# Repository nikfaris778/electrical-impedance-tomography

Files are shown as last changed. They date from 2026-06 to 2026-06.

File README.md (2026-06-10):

# Electical Impedance Tomography with Embroidered Electrodes





## 📌 Project Overview
This repository contains the MicroPython firmware and MATLAB simulation scripts for a 16-channel, 3D Electrical Impedance Tomography (EIT) system. Developed as part of a Master of Engineering (MEng) thesis, the project aimed to bridge the gap between low-cost analog hardware and true volumetric impedance imaging using custom CNC-embroidered textile electrodes (HC40 silver-plated thread).

Due to hardware compliance voltage limitations discovered in the V2.0 PCB iteration, the physical system was mathematically validated via synthetic forward modeling. The MATLAB scripts provided here rigorously prove the viability of the system's 3D cross-planar opposite-drive architecture against simulated hardware noise floors.

## 📂 Repository Structure

```text
├── /firmware                  # MicroPython code for the RP2040 (Raspberry Pi Pico)
│   ├── ad5933_wakeup.py       # AD5933 initialisation
│   ├── eit_driver.py          # I2C driver for the AD5933 Impedance Converter
│   └── MUX_control.py         # GPIO routing logic for the 16-channel matrix
│
├── /simulations               # MATLAB scripts using the EIDORS toolbox
│   ├── ValidationCode.m       # Core 3D EIT simulation (Single Target)
│   ├── SpatialComparison.m    # Multi-quadrant spatial variance loop
│   └── README_Simulations.md  # Specific instructions for EIDORS dependencies
│
├── /hardware_docs             # Schematics and PCB Layouts
│   ├── EIT_CONNECTIONS.pdf    # Patient protection block layout
│   ├── EIT_CURRENTSTAGE.pdf   # Analogue front end layout
│   ├── EIT_MULTICONTROLLER.pdf # Pi Pico 2 arrangement with pins
│   ├── EIT_MUXERS.pdf         # Multiplexer routing arrangement
│   └── EIT_board.PcbPrj       # Altium PCB project
└── README.md                  # This document
```
## 🧠 System Architecture
1. Hardware & Firmware Topology
- The physical system utilizes a four-pole (Kelvin) measurement strategy to mathematically negate the high and variable contact impedance ($Z_{contact}$) of the dry textile electrodes.
- Excitation Stage: Enhanced Howland Current Pump (designed for 1mA AC).
- Sensing Stage: AD8221 Instrumentation Amplifier.
- Impedance Converter: AD5933.
- Firmware Protocol: The MicroPython state machine dictates a dual-ring, cross-planar opposite-drive sequence (skip 8). This forces out-of-plane vertical current density vectors ($J_z$) critical for depth-resolved 3D tomography.

2. MATLAB / EIDORS Simulation
To validate the architecture, the MicroPython switching matrix was algorithmically mirrored in EIDORS.
- Noise Injection: Additive White Gaussian Noise (AWGN) at 40dB SNR was injected to simulate the real-world thermal noise limits of the AD8221.
- Inverse Solver: The system utilizes Time-Difference EIT with NOSER Regularization to compensate for the inherently low central sensitivity of the Jacobian matrix, successfully isolating 3D volumetric anomalies.

## 🚀 Getting Started
# Running the EIDORS Simulations
1. Ensure you have MATLAB installed.
2. Download and install the EIDORS 3.11 Toolbox.
3. In the MATLAB console, initialize EIDORS by running:
```matlab
run /path/to/eidors/startup.m
```
4. Open and run validation_3D.m to generate the 3D thresholded tomograms and 2D cross-sectional slices.
# Flashing the Firmware
1. Flash your Raspberry Pi Pico with the latest MicroPython UF2 bootloader.
2. Open the /firmware directory in an IDE like Thonny.
3. Upload main.py, ad5933.py, and mux_control.py to the Pico's root directory.

## ⚠️ Known Hardware Limitations & V3.0 Roadmap
This section documents critical system bring-up findings for future researchers.The V2.0 hardware iteration experienced a severe power domain mismatch ("Compliance Voltage Paradox"). The $\pm 9\text{V}$ analog supply required by the Howland Current Pump to drive high-impedance biological loads forward-biased the internal ESD diodes of the 3.3V CD74HC4067 multiplexers, causing catastrophic CMOS latch-up.

# V3.0 Recommendations:
1. Routing Matrix: Replace the logic-level CMOS multiplexers with high-voltage bipolar analog switches (e.g., Analog Devices ADG1406 or ADG1606) powered directly from the $\pm 9\text{V}$ analog rails.
2. Textile Interfaces: Implement active-electrode buffer topologies directly on the embroidered fabric substrate to combat the long-term oxidation of the HC40 silver thread.
3. Verification: Mandate SPICE transient analysis prior to Gerber generation to ensure safe mixed-signal boundary transitions.

## 📝 License
This project is open-source and available under the MIT License.

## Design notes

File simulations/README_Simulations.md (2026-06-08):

# Synthetic Validation Environment (EIDORS 3D)

This directory contains the MATLAB simulation scripts utilized to mathematically validate the 3D opposite-drive architecture of the EIT system. 

Because physical biological validation was precluded by a power domain mismatch (CMOS latch-up) on the V2.0 hardware, these scripts serve as the definitive proof of the system's underlying firmware state machine and analog sensitivity limits.

## 🧰 Prerequisites
To run these scripts, you must have the following installed:
* **MATLAB** (Tested on R2022a and newer)
* **EIDORS Toolbox** (Electrical Impedance Tomography and Diffuse Optical Tomography Reconstruction Software) - Version 3.11 or newer.

[Download EIDORS here](http://eidors3d.sourceforge.net/download.shtml)

## ⚙️ Setup Instructions
EIDORS must be initialized in your MATLAB workspace before running the simulation scripts.
1. Download and extract the EIDORS toolbox to your local machine.
2. Open MATLAB.
3. In the command window, run the EIDORS startup script:
   ```matlab
   run('C:\Path\To\Your\eidors3.11\eidors\startup.m')
4. You should see EIDORS: <Version> print in the console. You are now ready to run the simulations.

## 📄 File Manifest
```text
ValidationCode.m
```
The core validation script. It builds a 16-electrode, dual-ring cylindrical mesh and simulates a central non-conductive inclusion (representing an acrylic rod). It applies the 4-pole cross-planar firmware protocol, injects hardware noise, and outputs a thresholded 3D isosurface and 2D Z-axis cross-sections.

```text
SpatialComparison.m
```
A multi-target iterative script. It loops the forward and inverse solvers across three distinct XY coordinates (Dead Center, Top-Left, Bottom-Right) and generates a side-by-side comparative plot. This formally proves that the NOSER-regularized solver is robust against the inherently low central sensitivity of the EIT Jacobian matrix.

## 🎛️ Key Parameters for Experimentation
If you wish to modify the simulations to test different hardware constraints, look for the following variables in the scripts:
1. SNR_dB (Default: 40): Controls the Additive White Gaussian Noise (AWGN). 40dB represents the calculated thermal noise floor and quantization error of the V2.0 AD8221/AD5933 frontend. Lowering this value simulates a noisier PCB.
2. imdl.hyperparameter.value (Default: 1.0): The $\lambda$ tuning knob for the NOSER regularization algorithm.
   - Increase this value (e.g., 10.0) to heavily penalize boundary noise (results in a blurry, over-regularized image).
   - Decrease this value (e.g., 0.1) to reduce the penalty (results in high spatial resolution but severe peripheral noise artifacts).

## ⚠️ Important Note on Spatial Coordinates
The simulated saline tank has an absolute radius of 1.0. When modifying the $X$ and $Y$ coordinates of the acrylic rod, ensure that the outer edge of the rod does not exceed the tank boundary.If the condition sqrt(X^2 + Y^2) + Radius > 1.0 is met, the inclusion will physically clip outside the finite element mesh, and the solver will throw a NaN boundary exception.

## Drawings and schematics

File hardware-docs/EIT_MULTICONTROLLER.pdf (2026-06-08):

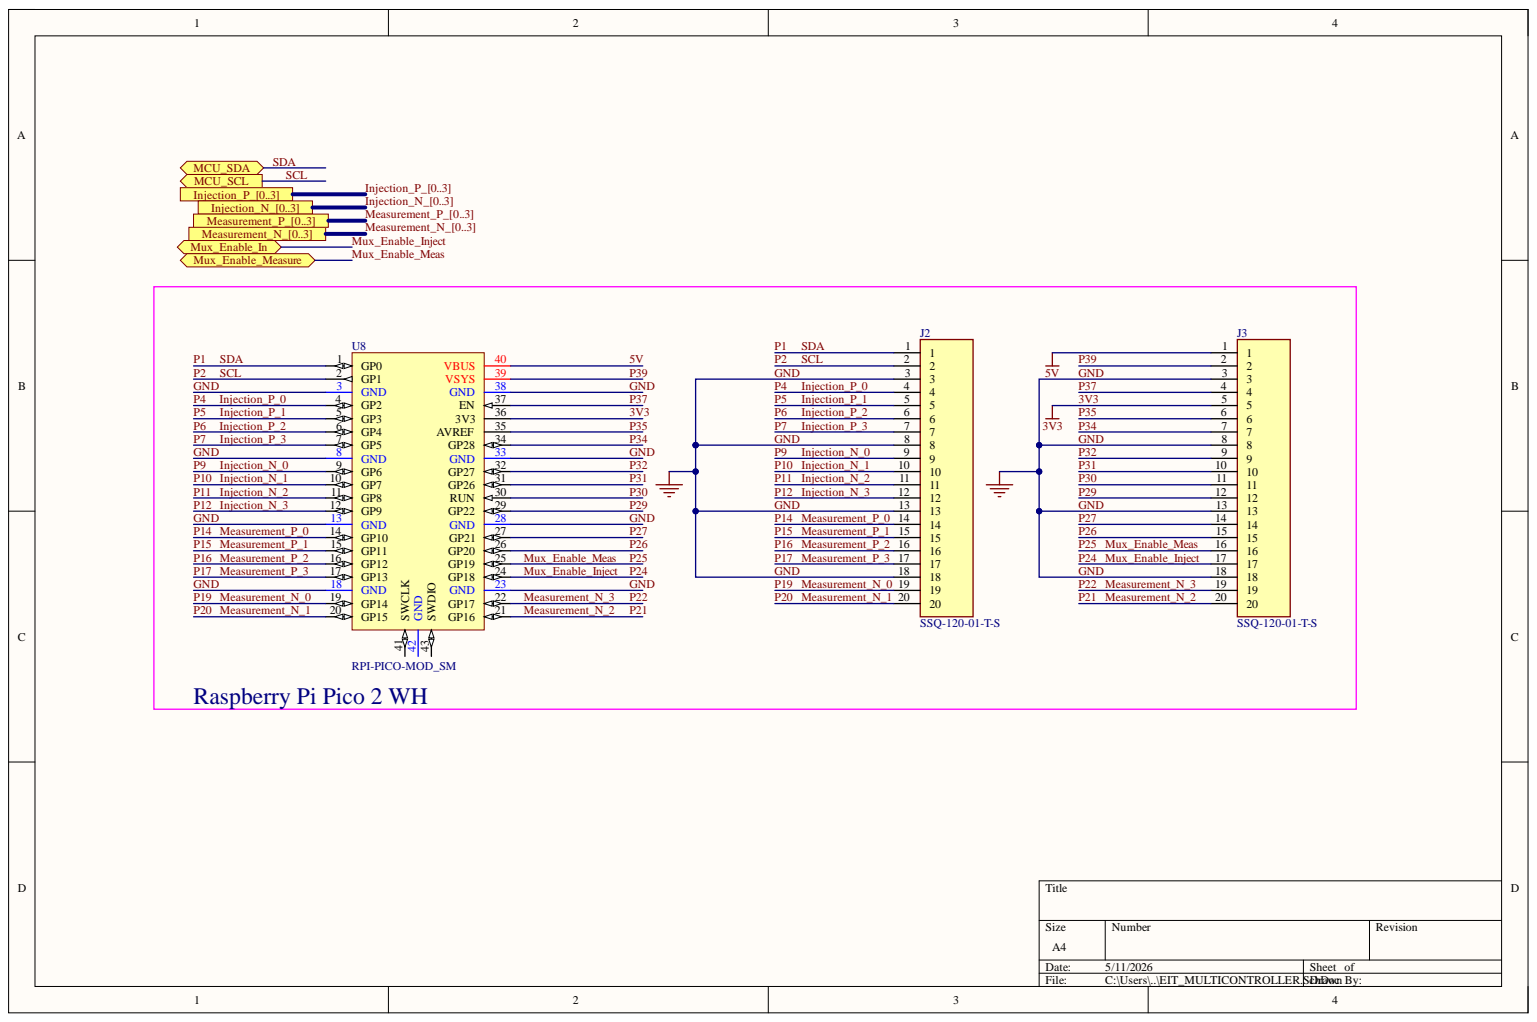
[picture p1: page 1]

Raspberry Pi Pico 2 WH

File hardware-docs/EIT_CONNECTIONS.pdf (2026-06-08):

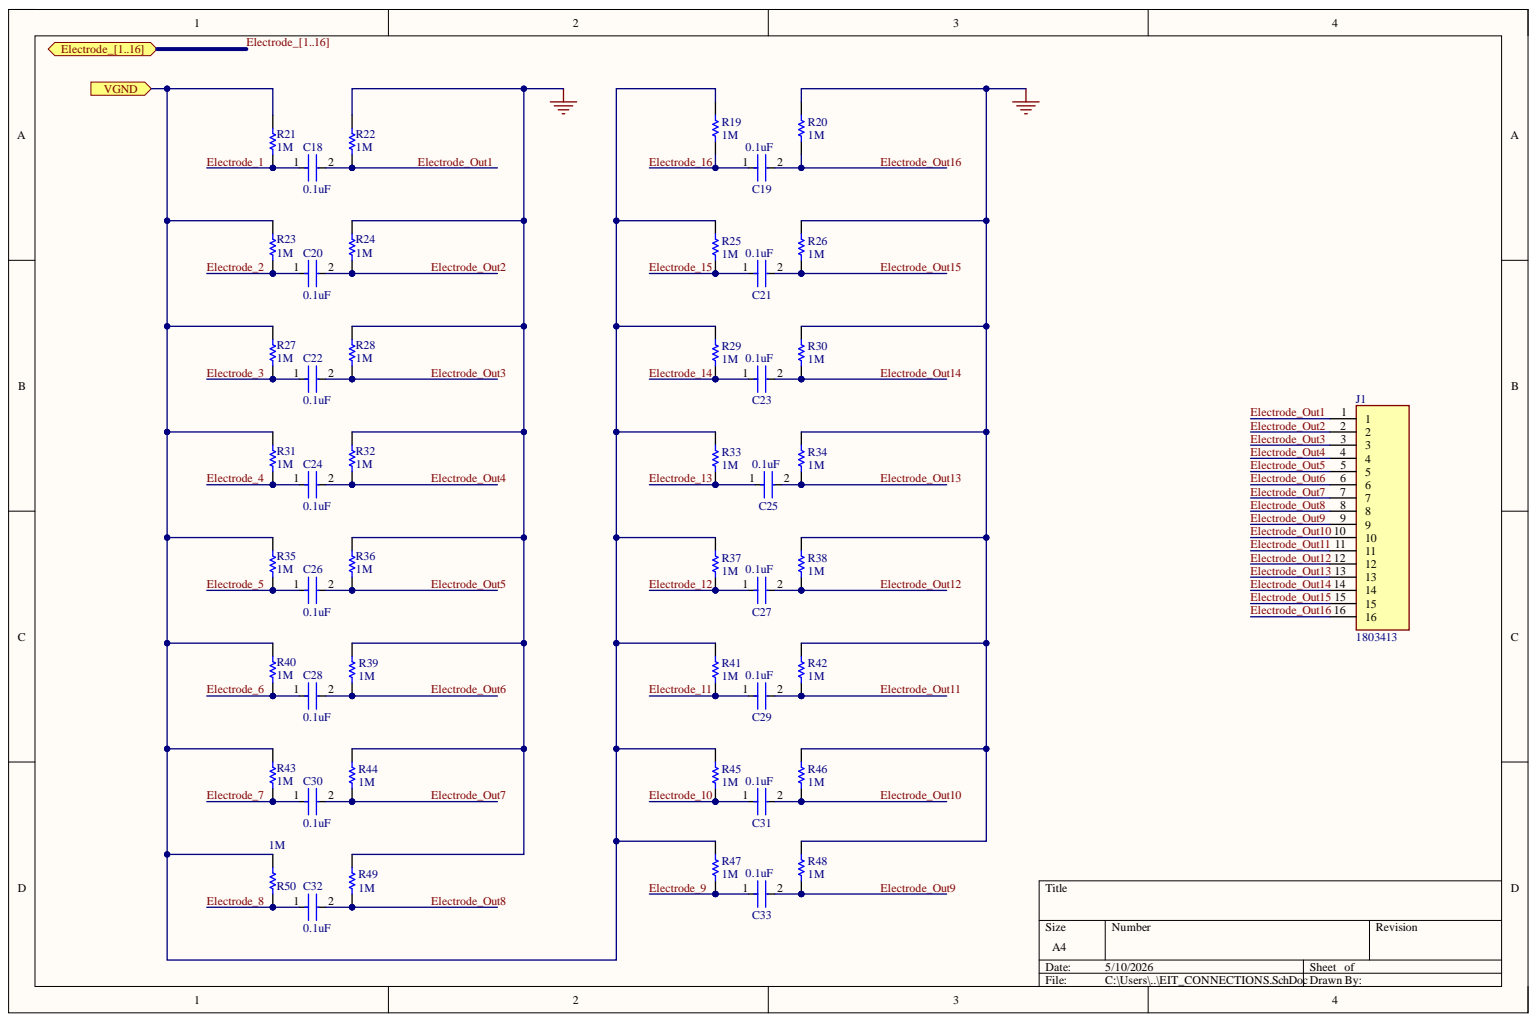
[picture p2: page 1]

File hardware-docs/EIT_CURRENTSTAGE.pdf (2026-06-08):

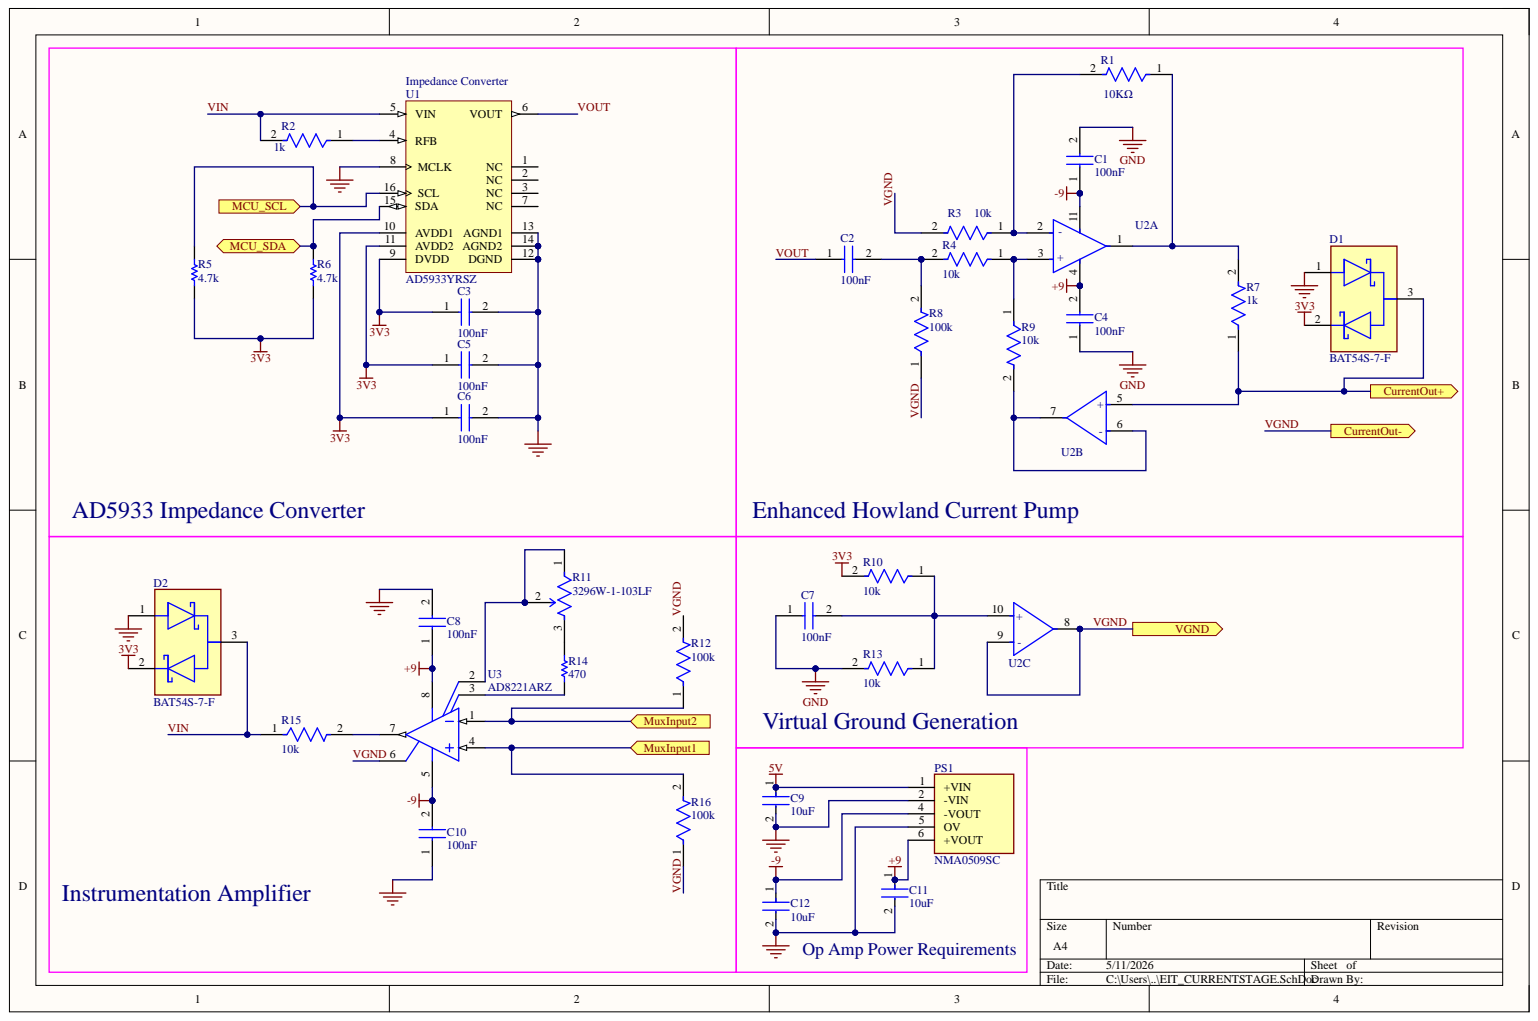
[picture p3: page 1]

AVDD2 11

R5 4.7k | DVDD 9

-VIN 2

10uF | -VOUT 4

OV 5
+VOUT 6

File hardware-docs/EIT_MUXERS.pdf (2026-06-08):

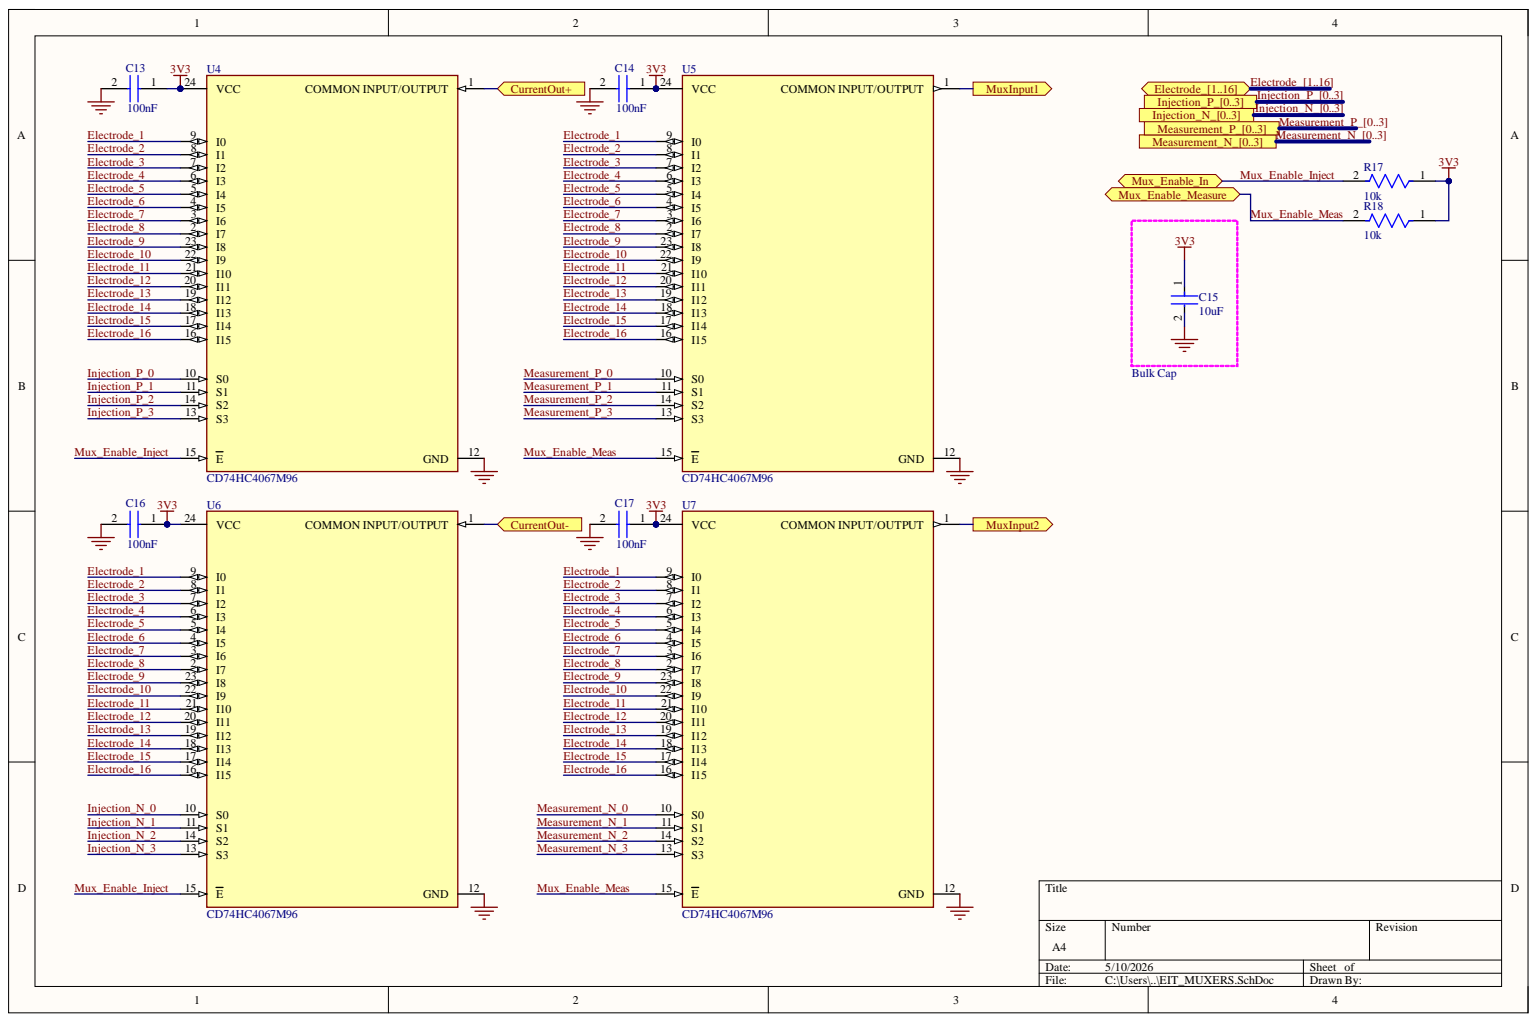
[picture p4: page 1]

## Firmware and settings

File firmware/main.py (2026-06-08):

import machine
import time

# --- Import your custom modules ---
from ad5933_driver import AD5933_EIT
from eit_routing import generate_eit_sequence

# 1. Initialize your hardware objects
chip = AD5933_EIT()
routing_table = generate_eit_sequence()

# 2. Setup your Pico MUX Pins here
# mux_source = [...]
# mux_sink = [...]
# etc...

def run_phase_5_calibration():
    print("Starting Calibration on Dummy Resistor...")
    # You will command the MUXes to Channels 0 and 1 here
    # You will trigger an I2C read from the AD5933 here
    # chip.calibrate(1000, raw_real, raw_imag)

def run_phase_6_sweep():
    print("Starting Full 16-Channel Sweep...")
    frame_data = []
    
    for step in routing_table:
        src, snk, meas_p, meas_n = step
        # 1. Switch MUX pins using src, snk, meas_p, meas_n
        # 2. Trigger AD5933 I2C read
        # 3. Calculate impedance: z = chip.calculate_impedance(real, imag)
        # 4. frame_data.append(z)
        
    print("Sweep Complete. Data:", frame_data)

# --- Main Execution Loop ---
run_phase_5_calibration()
# run_phase_6_sweep()

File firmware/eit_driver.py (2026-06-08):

from machine import Pin, I2C
import time
import struct
import json

class AD5933:
    """Hardware Abstraction Layer for the AD5933 Impedance Converter."""
    ADDR = 0x0D
    
    # Register Map
    REG_CTRL_HB = 0x80
    REG_CTRL_LB = 0x81
    REG_START_FREQ_1 = 0x82
    REG_FREQ_INC_1 = 0x85
    REG_NUM_INC_1 = 0x88
    REG_SETTLING_CYCLES_1 = 0x8A
    REG_STATUS = 0x8F
    REG_REAL_DATA_1 = 0x94
    REG_IMAG_DATA_1 = 0x96

    # Control Commands
    CTRL_STANDBY = 0xB0
    CTRL_INIT_START_FREQ = 0x10
    CTRL_START_FREQ_SWEEP = 0x20
    CTRL_INC_FREQ = 0x30
    
    def __init__(self, i2c_bus, ext_clk=16776000):
        self.i2c = i2c_bus
        self.clk = ext_clk
        self.verify_connection()
        self.reset()

    def verify_connection(self):
        devices = self.i2c.scan()
        if self.ADDR not in devices:
            raise RuntimeError("AD5933 not found on I2C bus. Check 3V3 rail and SDA/SCL pull-ups.")
        print("AD5933 verified at 0x0D.")

    def write_reg(self, reg, value):
        self.i2c.writeto_mem(self.ADDR, reg, bytes([value]))

    def read_reg(self, reg):
        return self.i2c.readfrom_mem(self.ADDR, reg, 1)[0]

    def reset(self):
        # Reset command to Control Register Low Byte
        self.write_reg(self.REG_CTRL_LB, 0x10)
        time.sleep_ms(10)
        self.set_standby()

    def set_standby(self):
        self.write_reg(self.REG_CTRL_HB, self.CTRL_STANDBY)

    def program_sweep(self, start_hz, inc_hz, num_inc, settling_cycles):
        """Calculates and loads the 24-bit frequency words."""
        # Calculate Start Frequency Code
        start_code = int((start_hz / (self.clk / 4)) * (2**27))
        self.write_reg(self.REG_START_FREQ_1, (start_code >> 16) & 0xFF)
        self.write_reg(self.REG_START_FREQ_1 + 1, (start_code >> 8) & 0xFF)
        self.write_reg(self.REG_START_FREQ_1 + 2, start_code & 0xFF)

        # Calculate Increment Code
        inc_code = int((inc_hz / (self.clk / 4)) * (2**27))
        self.write_reg(self.REG_FREQ_INC_1, (inc_code >> 16) & 0xFF)
        self.write_reg(self.REG_FREQ_INC_1 + 1, (inc_code >> 8) & 0xFF)
        self.write_reg(self.REG_FREQ_INC_1 + 2, inc_code & 0xFF)

        # Number of increments (9-bit limit, max 511)
        self.write_reg(self.REG_NUM_INC_1, (num_inc >> 8) & 0x01)
        self.write_reg(self.REG_NUM_INC_1 + 1, num_inc & 0xFF)

        # Settling time cycles (D10-D9 for multiplier, D8-D0 for cycles)
        # Using 1x multiplier for standard EIT frequencies
        self.write_reg(self.REG_SETTLING_CYCLES_1, (settling_cycles >> 8) & 0x07)
        self.write_reg(self.REG_SETTLING_CYCLES_1 + 1, settling_cycles & 0xFF)

    def measure_single_point(self):
        """Executes a single point measurement with strict polling."""
        self.write_reg(self.REG_CTRL_HB, self.CTRL_INIT_START_FREQ)
        time.sleep_ms(5) # Allow internal DC bias to settle
        self.write_reg(self.REG_CTRL_HB, self.CTRL_START_FREQ_SWEEP)

        # Poll Status Register for Valid Data (Bit 1)
        timeout = time.ticks_add(time.ticks_ms(), 100)
        while not (self.read_reg(self.REG_STATUS) & 0x02):
            if time.ticks_diff(timeout, time.ticks_ms()) < 0:
                raise TimeoutError("AD5933 conversion timed out.")

        # Read 16-bit Two's Complement Data
        real_high = self.read_reg(self.REG_REAL_DATA_1)
        real_low = self.read_reg(self.REG_REAL_DATA_1 + 1)
        imag_high = self.read_reg(self.REG_IMAG_DATA_1)
        imag_low = self.read_reg(self.REG_IMAG_DATA_1 + 1)

        real = struct.unpack('>h', bytes([real_high, real_low]))[0]
        imag = struct.unpack('>h', bytes([imag_high, imag_low]))[0]

        self.set_standby()
        return real, imag

class MUX_Matrix:
    """Manages the 16 independent GPIOs for the 4-Pole MUX array."""
    def __init__(self):
        # Mapped strictly to schematic Multicontroller_9.jpg
        self.inj_p_pins = [Pin(i, Pin.OUT) for i in (2, 3, 4, 5)]
        self.inj_n_pins = [Pin(i, Pin.OUT) for i in (6, 7, 8, 9)]
        self.meas_p_pins = [Pin(i, Pin.OUT) for i in (10, 11, 12, 13)]
        self.meas_n_pins = [Pin(i, Pin.OUT) for i in (14, 15, 16, 17)]
        
        # Enable Pins (Active Low)
        self.en_inject = Pin(18, Pin.OUT, value=1) 
        self.en_measure = Pin(19, Pin.OUT, value=1)

    def disable_all(self):
        """Break-before-make absolute enforcement."""
        self.en_inject.value(1)
        self.en_measure.value(1)
        time.sleep_us(10) # 10us guard band for logic switching

    def set_address(self, pins, channel):
        """Writes binary address to specific MUX S-lines."""
        for i in range(4):
            pins[i].value((channel >> i) & 1)

    def route_frame(self, inj_p, inj_n, meas_p, meas_n):
        """Executes a surgical 4-pole routing change."""
        self.disable_all()
        
        self.set_address(self.inj_p_pins, inj_p)
        self.set_address(self.inj_n_pins, inj_n)
        self.set_address(self.meas_p_pins, meas_p)
        self.set_address(self.meas_n_pins, meas_n)
        
        # Re-enable the paths
        self.en_inject.value(0)
        self.en_measure.value(0)
        
        # Settle delay for the Howland Pump's Virtual Ground RC constant
        time.sleep_us(500)
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

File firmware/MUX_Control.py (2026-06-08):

# MUX control tests
from machine import Pin
import time

# 🚨 REPLACE these numbers with your actual GP pin numbers! 🚨
# Group them by MUX to make your life easier when probing.
mux_1_pins = [Pin(2, Pin.OUT), Pin(3, Pin.OUT), Pin(4, Pin.OUT), Pin(5, Pin.OUT)]
mux_2_pins = [Pin(6, Pin.OUT), Pin(7, Pin.OUT), Pin(8, Pin.OUT), Pin(9, Pin.OUT)]
mux_3_pins = [Pin(10, Pin.OUT), Pin(11, Pin.OUT), Pin(12, Pin.OUT), Pin(13, Pin.OUT)]
mux_4_pins = [Pin(14, Pin.OUT), Pin(15, Pin.OUT), Pin(16, Pin.OUT), Pin(17, Pin.OUT)]

all_mux_pins = mux_1_pins + mux_2_pins + mux_3_pins + mux_4_pins
 
print("Starting 16-Pin MUX diagnostic.")
print("Check MUX 1, then MUX 2, etc. Take your time.")
print("-------------------------------------------------------------")

try:
    while True:
        print("--> Driving ALL 16 pins HIGH (3.3V)")
        for pin in all_mux_pins:
            pin.value(1)
        time.sleep(8)  # 8 seconds to give you time to probe  
        
        print("--> Driving ALL 16 pins LOW (0V)")
        for pin in all_mux_pins:
            pin.value(0)
        time.sleep(8) 

except KeyboardInterrupt:
    for pin in all_mux_pins:
        pin.value(0)
    print("\nTest stopped. Pins grounded.")
